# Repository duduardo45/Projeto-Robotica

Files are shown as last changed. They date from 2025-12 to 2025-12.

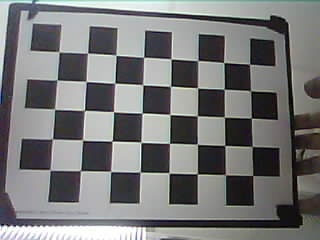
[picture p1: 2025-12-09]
ui/esp32_calibration_images/calib_20251209_100633.jpg

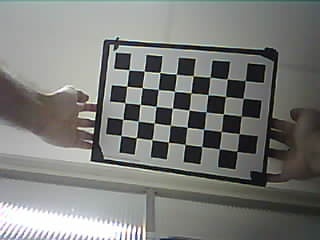
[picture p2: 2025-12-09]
ui/esp32_calibration_images/calib_20251209_100614.jpg

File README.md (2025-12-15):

# 🤖 Projeto Robótica - Empilhadeira Autônoma

Este repositório contém o projeto completo de uma empilhadeira autônoma desenvolvido para a disciplina de Robótica da PUC-Rio no semestre 2025.2. O curso tem como objetivo projetar e construir um robô funcional capaz de operar de forma autônoma e remota.

## 👥 Equipe

- Eduardo Eugênio de Souza
- Enzo Mediano
- Luísa Ferreira da Silveira
- Luiz Felipe Neves Batista

## 🎯 Objetivo do Projeto

O desafio proposto foi desenvolver uma empilhadeira autônoma com os seguintes requisitos:

- **Interface remota** para controle manual e controle de missão
- **Carga máxima**: 1 Kg
- **Altura máxima** do levantamento do garfo: 15 cm
- **Leitura de AprilTags** para localização no terreno e identificação de pallets
- **Alimentação** por baterias 18650

## Arquitetura do Sistema

O projeto foi desenvolvido seguindo uma abordagem integrada de hardware e software, dividido em 5 soluções principais:

---

## 1️⃣ Solução Mecânica

### Projeto e Construção

Todas as peças estruturais foram projetadas em CAD e impressas em 3D. Os arquivos STL estão disponíveis na pasta [Modelagem3D](Modelagem3D/).

#### **Componentes Mecânicos Projetados:**

**Garfo e Sistema de Elevação:**

- [Guia + Garfo - Part 1](<Modelagem3D/Guia%20+%20Garfo%20-%20Part%201%20(4).stl>) - Estrutura principal do garfo
- [Guia + Garfo - Part 2](<Modelagem3D/Guia%20+%20Garfo%20-%20Part%202%20(3).stl>) - Componente secundário do garfo
- [Guia + Garfo - Part 4](Modelagem3D/Guia%20+%20Garfo%20-%20Part%204.stl) - Suporte adicional
- Guia vertical de **15 cm** para elevação do garfo
- Sistema de polias para transmissão ([Polia - Part 1](Modelagem3D/Polia%20-%20Part%201.stl))

**Estrutura e Suportes:**

- [Case Baterias](Modelagem3D/Case_Baterias%20-%20Part%201.stl) - Compartimento para baterias 18650
- [Case Contrapeso](Modelagem3D/Case-Contrapeso%20-%20Part%202.stl) - Peso para balanceamento
- [Suporte ESP32 - Part 1](<Modelagem3D/Suporte%20esp32%20-%20Part%201%20(1).stl>) e [Part 2](<Modelagem3D/Suporte%20esp32%20-%20Part%202%20(1).stl>) - Fixação do microcontrolador
- [Roof Holder - Parts 1-4](Modelagem3D/) - Suportes para o teto do robô
- [Suporte Motor Elevação](Modelagem3D/suporte%20motor%20elevação%20-%20Part%201.stl) - Base do motor de elevação

#### **Modelagens Não Utilizadas:**

Algumas peças foram modeladas mas não foram utilizadas na montagem final:

- [Battery Support (Suporte de Bateria)](Modelagem3D/Battery%20Container%20Support.stl) - Não foi utilizado pois se tornou redundante, já que o compartimento de baterias conseguia ser travado através do teto (roof holder) e havia a necessidade de passagem de fios pela parte inferior do suporte.
- [Motor Holder (Suporte do Motor)](Modelagem3D/Motor%20Holder.stl) - Não houve tempo hábil para instalar o componente.
- [Polia](Modelagem3D/Polia%20-%20Part%201.stl) - A polia acabou não sendo utilizada, preferindo conectar o fio que levanta o garfo diretamente no motor.

#### **Limitações de Tempo na Montagem:**

1. **Motor Elevation Base** - Não foi impresso devido ao tempo limitado do projeto
2. **Roof (teto completo)** - Foi impresso, mas não montado. Esta peça seguraria o motor de elevação que ficaria em cima do roof holder. Como não foi implementada, o motor de elevação permaneceu dentro do chassis do robô
3. **Organização de fiação** - Como a câmera utilizada era integrada ao ESP32 e ele ficou posicionado no alto (em cima da guia), muitos fios ficaram expostos e desorganizados, comprometendo a estética do projeto. Com mais tempo, seria implementada uma calha para passagem de fios na guia
4. **Polia** - Preferimos conectar os fios diretamente ao motor de elevação, sem utilizar a polia impressa. Isso simplificou a montagem e evitou possíveis problemas mecânicos"

### Montagem Final

O robô foi montado com:

- Garfo móvel com guia de elevação de 15cm
- sistema de passagem dos fios que puxam o garfo
- Compartimento de baterias integrado
- Teto para o chassis (roof holder)
- Contrapeso para balanceamento
- ESP32 com câmera posicionado na parte superior

---

## 2️⃣ Solução Eletrônica

### Componentes Utilizados

#### **Microcontrolador:**

- **ESP32-S3 DevKitC-1** (16MB Flash, PSRAM)
  - WiFi integrado para comunicação
  - Câmera OV2640 integrada (320x240)
  - 2x Timer hardware para controle preciso
  - Múltiplos canais PWM

#### **Sistema de Alimentação:**

- **3x Baterias 18650** em série → **12V total**
  - **12V direto** para os motores DC
  - ⚠️ **BMS não implementado** - Por limitação de tempo, não foi utilizado Battery Management System. Isso seria uma melhoria importante para segurança e longevidade das baterias

#### **Motorização:**

- **2x Motores DC com encoder** (locomoção)
  - 64 pulsos por rotação
  - Alimentação: 12V
  - Controle via Ponte H
- **1x Motor DC para elevação do garfo**
  - Hardware montado e conectado
  - ⚠️ Software não implementado

#### **Drivers e Interfaces:**

- **Ponte H (H-Bridge)** para controle bidirecional dos motores
  - Controle de direção (pinos IN1, IN2)
  - Controle de velocidade via PWM
  - Duas Ponte H (uma para motores de locomoção e uma para o de elevação)
- **Encoders ópticos** conectados via interrupção

## 3️⃣ Solução de Comunicação

### Arquitetura de Comunicação

O sistema utiliza uma arquitetura de três camadas:

```
[Frontend Web] ↔ [Backend Python] ↔ [ESP32]
   (React)      WebSocket/HTTP      WebSocket
```

### Protocolo de Comunicação

#### **ESP32 ↔ Backend Python:**

- **WebSocket** na porta 8000
- **Formato:** JSON (comandos e telemetria) + Binário (imagens)
- **Taxa de telemetria:** 20Hz (50ms)
- **Taxa de vídeo:** 5fps (200ms)

#### **Backend ↔ Frontend:**

- **WebSocket** para dados em tempo real
- **REST API** para comandos pontuais
- **Broadcast** de estado para múltiplos clientes

### Mecanismos de Fail-Safe

1. **Heartbeat System:**

   - Cliente deve enviar heartbeat a cada 200ms
   - Timeout de 3 segundos sem heartbeat → parada automática dos motores
   - Implementado via timestamp no ESP32

2. **Watchdog de Conexão:**

   - Detecção de desconexão WebSocket
   - Parada segura em caso de perda de comunicação

3. **Validação de Comandos:**
   - Limites de velocidade no firmware
   - Validação de JSON no backend

### Interface de Controle

- **Interface Web moderna** (React + TypeScript)
- **Controle manual** via botões de interface
- **Controle autônomo** via waypoints
- **Visualização em tempo real** de câmera e telemetria
- **Gráficos de debug** para ajuste de PID

---

## 4️⃣ Solução de Controle

### Controle em Malha Aberta vs Malha Fechada

O sistema implementa controle em **malha fechada** para os motores de locomoção, utilizando feedback dos encoders para correção contínua.

### 🎯 Controlador PID

O firmware implementa um controlador PID otimizado para cada roda:

#### **Componentes do Controlador:**

1. **Termo Proporcional (P):** `kp × erro`

   - Correção proporcional ao erro de velocidade
   - kp = 40.0 (ajustado experimentalmente)

2. **Termo Integral (I):** `ki × ∫erro·dt`

   - Elimina erro em regime permanente
   - ki = 30.0
   - **Anti-windup:** Limita integrador a ±6.0 para evitar saturação

3. **Feedforward (F):** `kf × velocidade_desejada`

   - Compensação antecipada da velocidade
   - kf = 10.0

4. **Termo Estático (S):** `ks`

   - Constante para vencer atrito estático inicial
   - ks = 120.0

5. **Dithering:**
   - Vibração de 25Hz (±70 PWM) para reduzir zona morta
   - Elimina stiction e melhora resposta em baixas velocidades

#### **Características do Sistema:**

- **Frequência de controle:** 33Hz (30ms de período)
- **Rampa de aceleração:** 0.4 m/s² máximo
- **Filtro passa-baixas:** α = 0.1 (suavização exponencial)
- **Encoders:** 64 pulsos/rotação
- **Thread-safe:** Mutex para proteção de variáveis compartilhadas

### 🗺️ Navegação e Localização

#### **Detecção de AprilTags:**

- Biblioteca `pupil_apriltags` para detecção
- Família de tags: 36h11
- Tamanho físico: 12cm
- Calibração de câmera: fx=298.3, fy=306.9, cx=158.8, cy=121.7

#### **Localização:**

- Cálculo de pose (x, y, θ) baseado em AprilTags detectadas
- Transformação 3D → 2D para navegação planar
- Fusão com odometria dos encoders

#### **Navegação Autônoma:**

- Waypoint navigation com correção de trajetória
- Controlador angular proporcional
- Tolerância: 5cm (posição), 0.5rad (orientação)
- Estados: idle, running, completed, error

---

## 5️⃣ Montagem Geral

### Processo de Montagem

A montagem do robô seguiu as seguintes etapas:

#### **1. Impressão 3D das Peças**

Todas as peças foram impressas utilizando os arquivos STL disponíveis:

- Estrutura do garfo e guias
- Compartimentos para eletrônica
- Suportes e fixações

#### **2. Montagem da Estrutura Base**

- Montagem do roof holder do robô
- Montagem do compartimento de baterias
- Instalação do contrapeso para balanceamento

#### **3. Montagem do Sistema de Elevação**

- Instalação da guia vertical (15cm)
- Fixação do garfo móvel
- Montagem do sistema onde passam os fios
- Conexão do motor de elevação (hardware pronto)

#### **4. Integração Eletrônica**

- Instalação do ESP32 no suporte superior
- Conexão da Ponte H aos motores
- Fiação das baterias (3x em série = 12V)
- Conexão dos encoders

#### **5. Limitações da Montagem**

**Problemas Estéticos:**

- Como a câmera é integrada ao ESP32 e foi posicionada no alto (em cima da guia), muitos fios ficaram expostos e desorganizados
- Isso comprometeu a aparência final do projeto
- **Solução planejada (não implementada):** Calha para passagem de fios na guia

**Componentes não Montados:**

- **Motor Elevation Base:** Não foi impresso por falta de tempo
- **Roof completo:** Foi impresso mas não montado. Esta peça seguraria o motor de elevação que ficaria em cima do roof holder
- Como resultado, o motor de elevação permaneceu dentro do chassis

**Sistema de Alimentação:**

- BMS (Battery Management System) não foi implementado
- Seria importante para segurança e longevidade das baterias
- Configuração atual: 3 baterias 18650 em série (12V total)

### Resultado Final

O robô foi montado com:

- ✅ Chassis estrutural completo
- ✅ Sistema de locomoção com 2 motores + encoders
- ✅ Garfo com guia de 15cm
- ✅ Sistema de passagem do fios
- ✅ ESP32 com câmera integrada
- ✅ Ponte H para controle dos motores
- ✅ Sistema de baterias (3x 18650 em série)
- ⚠️ Fiação exposta (sem calha organizadora)
- ⚠️ Motor de elevação sem software
- ⚠️ Roof não montado completamente

---

## 💻 Detalhes de Implementação de Software

### 🔧 Firmware ESP32 (C++)

Desenvolvido em C++ usando o framework Arduino para ESP32.

**Arquivos principais:**

- [main.cpp](src/main.cpp) - Loop principal e coordenação de sistemas
- [camera_pins.h](src/camera_pins.h) - Definição de pinos da câmera

### 🐍 Backend Python (FastAPI)

O servidor backend em Python atua como intermediário inteligente entre a interface do usuário e o robô.

**Arquivos principais:**

- [main.py](ui/main.py) - Servidor principal e lógica de controle
- [calibrate_camera.py](ui/calibrate_camera.py) - Calibração da câmera

**Arquivos para testes:**

- [fake_robot.py](ui/fake_robot.py) - Simulador para testes
- [simple_server.py](ui/simple_server.py) - Servidor simplificado
- [gabriel_client.py](ui/gabriel_client.py) - Cliente simples para testes

### ⚛️ Frontend Web (React + TypeScript)

Interface moderna e responsiva desenvolvida com React 18, TypeScript e Chakra UI.

**Funcionalidades:**

- Controle manual e autônomo
- Visualização de câmera em tempo real
- Gráficos de telemetria (velocidade, PID, PWM)
- Monitoramento de AprilTags
- Dashboard de estado do robô

**Arquivos principais:**

- [App.tsx](ui-frontend/src/App.tsx) - Componente principal
- [CameraFeed.tsx](ui-frontend/src/components/CameraFeed.tsx) - Visualização de vídeo
- [types.ts](ui-frontend/src/types.ts) - Definições de tipos
- [theme.ts](ui-frontend/src/theme.ts) - Configuração de tema

---

## ⚙️ Configuração e Execução

### ESP32 Firmware

```bash
# Instalar PlatformIO
pip install platformio

# Compilar e fazer upload
cd Projeto-Robotica
pio run --target upload
```

### Backend Python

```bash
cd ui
pip install -e .
python main.py
```

### Frontend

```bash
cd ui-frontend
pnpm install
pnpm dev
```

---

## 🎮 Modos de Operação

### 1. Modo Manual

- Controle direto via interface web ou cliente Python
- Comandos via botões de interface para movimento
- Feedback em tempo real de telemetria

### 2. Modo Autônomo

- Definição de waypoint de destino via interface
- Navegação automática com correção de trajetória
- Localização baseada em AprilTags
- Parada automática ao atingir objetivo

## 📊 Características Técnicas do Software

### Controle PID Otimizado

- **Frequência**: 33Hz (30ms de período)
- **Dithering**: implementado para redução de stiction
- **Anti-windup**: Clamp do integrador em ±6.0
- **Rampa**: Aceleração máxima de 0.4 m/s²
- **Filtro**: α = 0.1 para suavização exponencial

### Comunicação

- **Protocolo**: WebSocket (texto JSON + binário)
- **Telemetria**: 20Hz
- **Vídeo**: 5fps (320x240 JPEG)
- **Heartbeat**: 5Hz com timeout de 3s

### Visão Computacional

- **Tags**: Família AprilTag 36h11
- **Tamanho**: 12cm (físico)
- **Calibração**: Fx=298.3, Fy=306.9, Cx=158.8, Cy=121.7
- **Detecção**: Tempo real (<50ms por frame)

## ⚠️ Limitações e Trabalho Futuro

### ❌ O que não foi implementado

#### **Sistema de Elevação do Garfo**

Infelizmente, não tivemos tempo de implementar o código de controle para o motor de elevação do garfo. A **parte mecânica e eletrônica estava completa**, incluindo:

- Motor DC com encoder
- Sistema da passagem dos fios, guias e garfo impressas em 3D
- Driver de motor conectado ao ESP32

**O que faltou:** Implementação do código de controle no firmware, incluindo:

- Interface de comandos via WebSocket
- Controle de posição ou velocidade
- Limites de segurança (altura mínima/máxima)
- Integração com a interface gráfica

### 🚧 Desafios Encontrados

Durante o desenvolvimento, enfrentamos alguns desafios importantes que impactaram o desempenho do robô:

1. **Atrito excessivo no piso**

   - O tipo de piso utilizado nos testes apresentava muito atrito
   - Isso dificultou o movimento suave do robô
   - Exigiu ajustes constantes nos parâmetros do PID
   - Afetou a precisão da odometria

2. **Problemas mecânicos nas rodas**

   - As rodas não giravam perfeitamente livre
   - Havia resistência mecânica além do esperado
   - Possível desalinhamento ou fricção nos eixos
   - Zona morta maior que o ideal no sistema de acionamento

3. **Navegação autônoma imprecisa**

   - A navegação para pontos específicos não estava 100% precisa
   - Desvios acumulativos devido ao atrito e problemas mecânicos
   - Dificuldade em manter trajetória reta por longas distâncias
   - Necessidade de ajuste fino dos ganhos do controlador

4. **Latência na comunicação WiFi**
   - Atraso na transmissão de informações no modo manual
   - Possível instabilidade da conexão WiFi em tempo real
   - Impactou a responsividade e controle direto do robô
   - Comandos demoravam alguns milissegundos para chegar
   - Feedback de telemetria não era tão rápido quanto ideal

Estes problemas mecânicos, de atrito e de comunicação impactaram significativamente a performance do sistema autônomo e manual, demonstrando a importância da integração mecânica, eletrônica e de software em projetos de robótica.

### ✅ O que foi concluído com sucesso

1. **Sistema de locomoção**

   - Motores DC com controle PID implementado
   - Odometria funcional (com limitações pelo atrito)
   - Controle diferencial básico operacional

2. **Comunicação WiFi/WebSocket**

   - Conexão funcional (com latência perceptível no controle manual)
   - Protocolo bem definido e extensível

3. **Visão computacional**

   - Detecção confiável de AprilTags
   - Cálculo de pose implementado
   - Streaming de vídeo funcional

4. **Interface de usuário**

   - Interface moderna e intuitiva
   - Telemetria em tempo real
   - Gráficos de debug detalhados

5. **Navegação autônoma básica**
   - Waypoint navigation implementada
   - Correção de trajetória (com margem para melhorias)
   - Sistema de missões funcional

### 🔮 Melhorias Futuras

#### **Software - Comunicação**

- Otimizar comunicação WiFi para reduzir latência
- Implementar compressão de dados para mais rápida transmissão
- Aumentar frequência de heartbeat
- Otimizar protocolo WebSocket

#### **Software - Controle de Elevação**

- Implementar controle manual do garfo (subir/descer)
- Implementar controle autônomo do garfo em missões
- Integrar interface gráfica para controle da elevação

#### **Hardware e Mecânica**

- Pensar em estratégias para lidar com o atrito do piso
- Implementar BMS para segurança das baterias
- Imprimir as peças não montadas (Motor Elevation Base, Roof) e montá-las corretamente
- Adicionar sensor de fim de curso para detectar quando o pallet está posicionado
- Adicionar sensor ultrassônico para detecção de obstáculos

#### **Algoritmos Avançados**

- Implementar SLAM para mapeamento do ambiente
- Melhorar odometria com fusão de sensores (IMU)
- Adicionar planejamento de trajetória (A\*, RRT)
- Implementar pickup/place automático de pallets
- Adicionar sistema de filas de missões

---

## 🛠️ Dependências Principais

### ESP32

- Arduino Framework
- ArduinoJson (^7.0.4)
- ESP32 Camera (^2.0.4)
- WebSockets (^2.7.1)

### Python Backend

- FastAPI
- Uvicorn
- Websockets
- OpenCV (cv2)
- NumPy
- pupil-apriltags
- TurboJPEG

### Frontend

- React 18
- TypeScript
- Chakra UI
- Vite
- Lucide Icons

---

## 📝 Licença

Este projeto foi desenvolvido para fins educacionais como parte da disciplina de Robótica da PUC-Rio.

---

## 🙏 Agradecimentos

Agradecemos aos professores da disciplina de Robótica pelo suporte e orientação durante o desenvolvimento deste projeto desafiador.

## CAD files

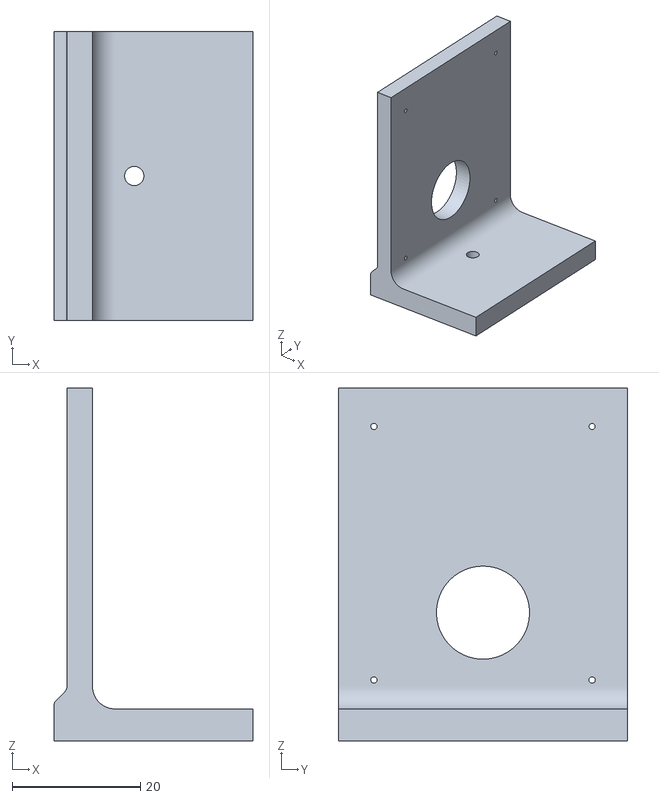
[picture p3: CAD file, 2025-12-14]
Modelagem3D/Motor Holder.stl
31.0 x 45.0 x 55.0

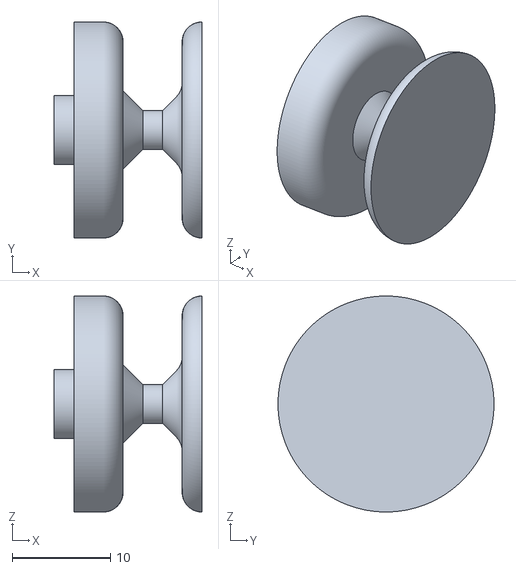
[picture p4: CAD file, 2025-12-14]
Modelagem3DNaoUtilizado/Polia - Part 1.stl
15.0 x 21.9 x 21.9

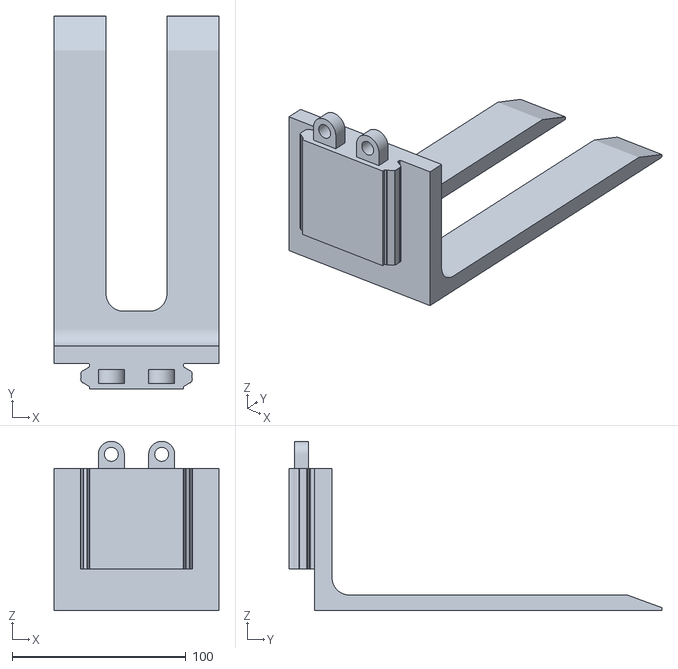
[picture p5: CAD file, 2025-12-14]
Modelagem3D/Guia + Garfo - Part 1 (4).stl
95.0 x 214.8 x 97.5

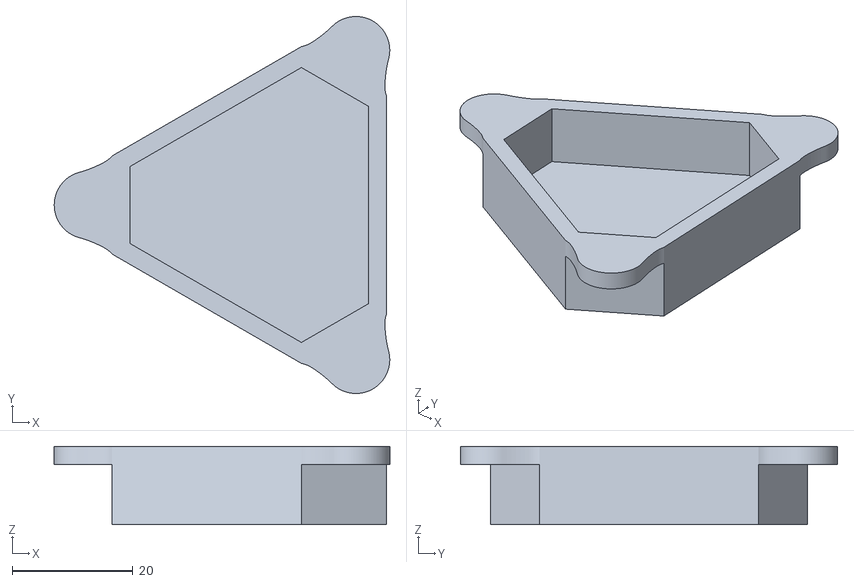
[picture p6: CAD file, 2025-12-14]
Modelagem3D/Case-Contrapeso - Part 2.stl
55.6 x 62.5 x 13.0

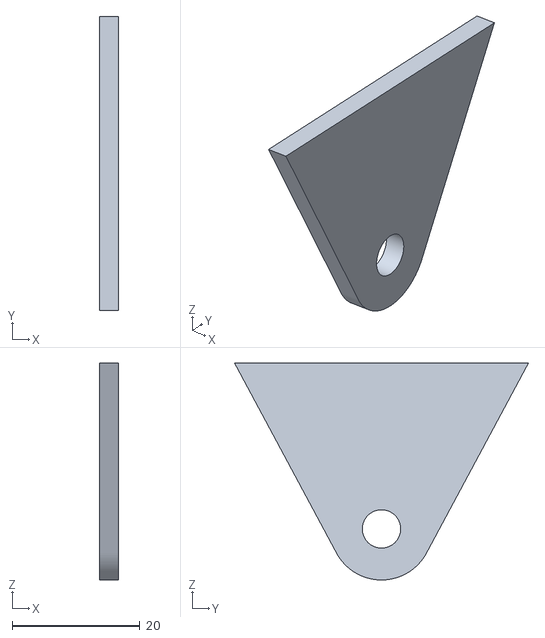
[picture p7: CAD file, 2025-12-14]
Modelagem3D/Roof holder - Part 2.stl
3.00 x 46.1 x 34.0

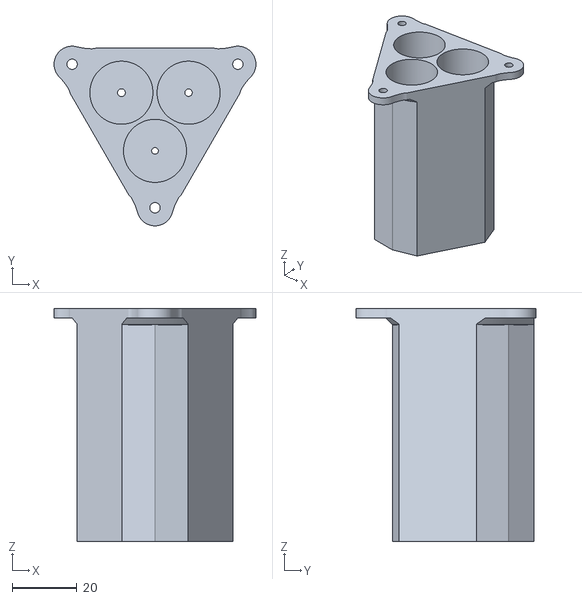
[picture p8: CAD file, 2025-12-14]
Modelagem3D/Case_Baterias - Part 1.stl
62.5 x 55.6 x 72.1

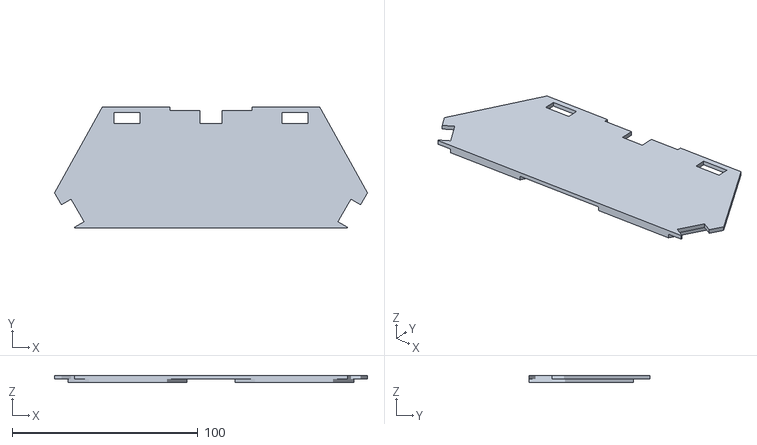
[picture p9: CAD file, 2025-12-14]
Modelagem3D/Battery Container Support.stl
168.5 x 65.3 x 4.00

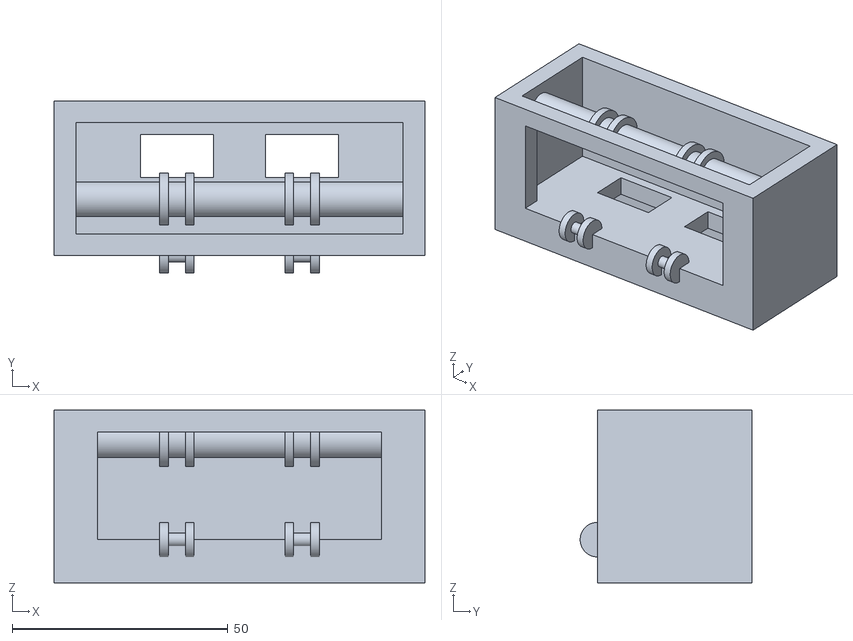
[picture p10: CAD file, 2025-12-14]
Modelagem3D/Guia + Garfo - Part 4.stl
86.0 x 39.8 x 40.0

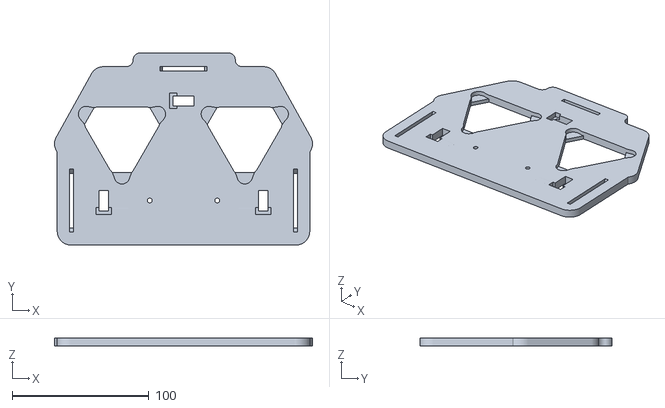
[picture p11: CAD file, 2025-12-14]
Modelagem3D/Roof holder - Part 4.stl
188.5 x 140.3 x 6.04

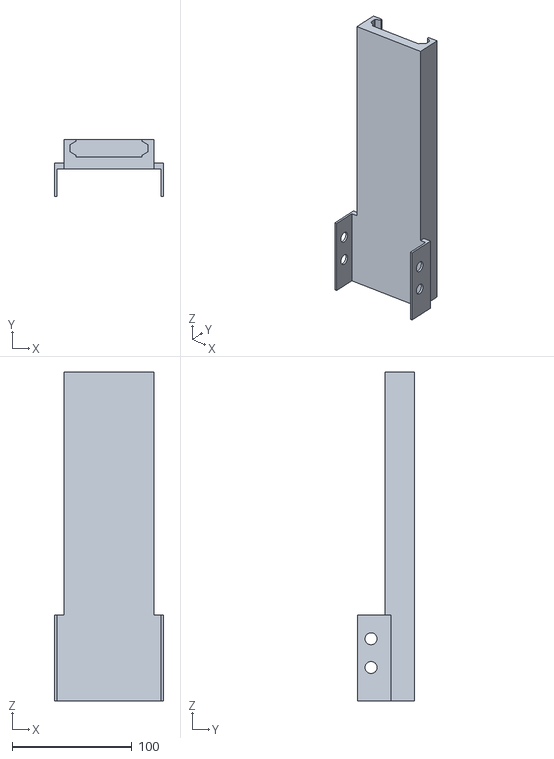
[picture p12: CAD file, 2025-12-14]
Modelagem3D/Guia + Garfo - Part 2 (3).stl
91.0 x 48.0 x 275.0

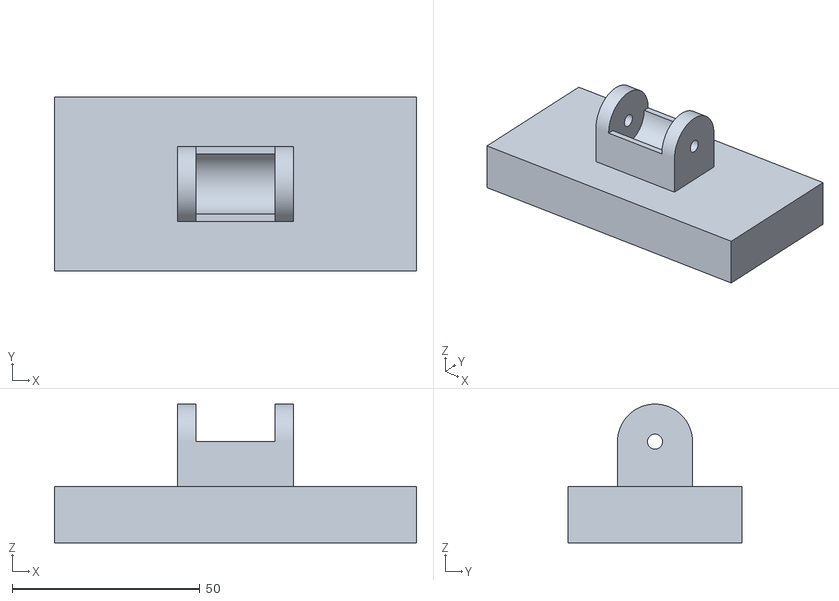
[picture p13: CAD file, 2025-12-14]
Modelagem3D/Suporte esp32 - Part 1 (1).stl
96.5 x 46.4 x 37.0

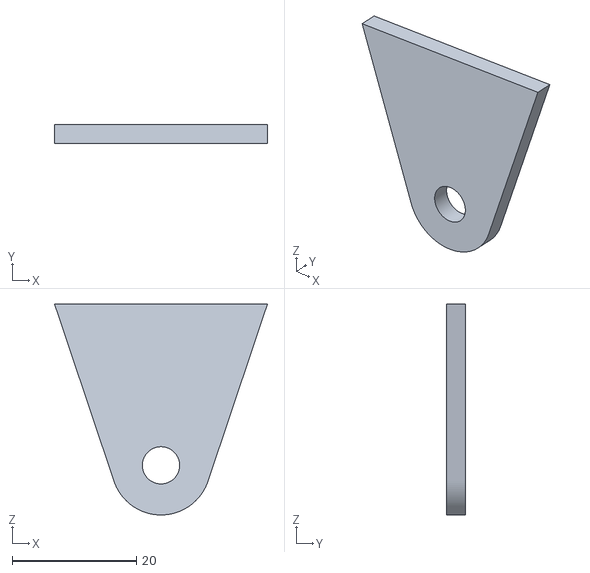
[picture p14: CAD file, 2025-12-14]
Modelagem3D/Roof holder - Part 3.stl
34.3 x 3.00 x 34.0

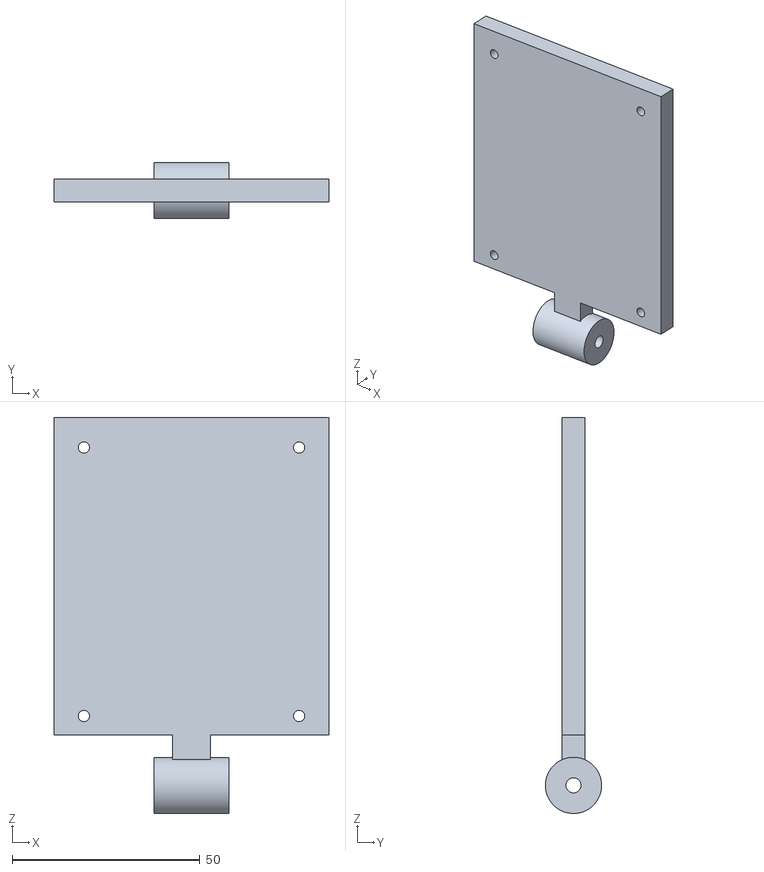
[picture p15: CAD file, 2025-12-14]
Modelagem3D/Suporte esp32 - Part 2 (1).stl
73.2 x 15.0 x 105.6

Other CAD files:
Modelagem3D/suporte motor elevação - Part 1.stl
Modelagem3D/Roof holder - Part 1.stl

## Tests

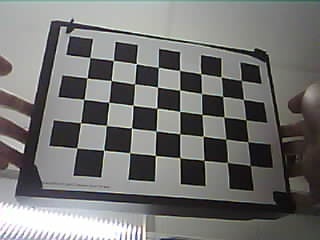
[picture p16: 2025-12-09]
ui/esp32_calibration_images/calib_20251209_100652.jpg

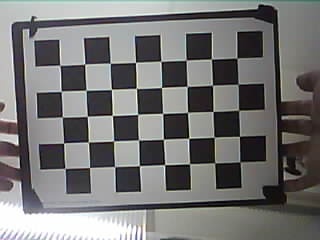
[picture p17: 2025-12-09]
ui/esp32_calibration_images/calib_20251209_100625.jpg

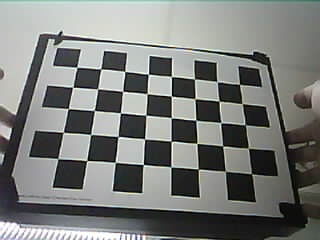
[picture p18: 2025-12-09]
ui/esp32_calibration_images/calib_20251209_100638.jpg

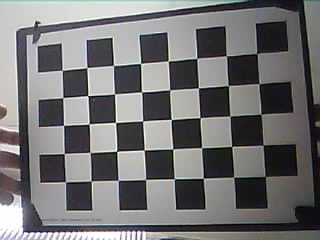
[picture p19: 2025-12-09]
ui/esp32_calibration_images/calib_20251209_100629.jpg

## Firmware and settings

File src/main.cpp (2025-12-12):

#include <Arduino.h>
#include <ArduinoJson.h>
#include <WebSocketsServer.h>
#include <WiFi.h>
#include <esp_camera.h>

#include "camera_pins.h"
// #include "credentials.h"
// DO NOT DO NEOPIXEL WRITE BECAUSE WE COULD BE USING ITS PIN
//
// CONFIGURATION
//

// --- Networking ---
const uint16_t WS_PORT = 8000;

const char *AP_SSID = "ESP32_Robot_AP";
const char *AP_PASS = "robot1234";  // Must be at least 8 chars

// #define WHEELS_DISABLED
// --- Physics & Tuning ---
// Left Wheel
#define PIN_ENC_L 21
#define PIN_PWM_L 1
#define PIN_IN1_L 44
#define PIN_IN2_L 2
#define PWM_CHAN_L 2  // Channel 0 is taken by Camera! Using 2.
#define TUNING_L {120.0, 10.0, 40.0, 30.0}  // {ks, kf, kp, ki}

// Right Wheel. it has a bigger ks because it has more static friction
#define PIN_ENC_R 47
#define PIN_PWM_R 42
#define PIN_IN1_R 41
#define PIN_IN2_R 48
#define PWM_CHAN_R 3
#define TUNING_R {120.0, 10.0, 40.0, 30.0}

#define WHEEL_RADIUS_MM 49.67
#define PULSES_PER_ROT 64.0
#define PWM_LIMITS {0, 255}
#define SPEED_DEADBAND 0.01
#define INTEGRATOR_CLAMP 6.0
// SPEED_FILTER_ALPHA the lower you make it, the slower is the exponential
// average:
#define SPEED_FILTER_ALPHA 0.1

#define MAX_ACCEL 0.4
#define DITHER_MAGNITUDE 70.0

// --- Timing ---
#define CONTROL_PERIOD_MICROS 30e3
#define TELEMETRY_PERIOD_MICROS \
  50e3  // to get accurate telemetry, maybe this needs to be faster than the
        // control loop?
#define FRAME_STREAM_PERIOD_MICROS 200e3
#define PWM_FREQ 5000
#define PWM_RES 8
#define HEARTBEAT_TIMEOUT_MICROS 3000e3
//

// DATA STRUCTURES
//

portMUX_TYPE timerMux = portMUX_INITIALIZER_UNLOCKED;
// Mutex for protecting variables shared between loop() and motorTask()
portMUX_TYPE sharedVarMux = portMUX_INITIALIZER_UNLOCKED;

esp_timer_handle_t controlTimer;

struct PidConfig {
  double ks, kf, kp, ki;
};

// --- THREAD SAFETY BRIDGE ---
struct MotorCommand {
  double targetL;
  double targetR;
  int64_t lastHeartbeat;
};

struct MotorState {
  double encL, rawL, filtL, targetL;
  double encR, rawR, filtR, targetR;
  double debug_fL, debug_pL, debug_iL, debug_outL;
  double debug_fR, debug_pR, debug_iR, debug_outR;
};

// Global instances of the bridge data
MotorCommand sharedCommand = {0, 0, 0};
MotorState sharedState = {0};

//

// WHEEL CONTROLLER CLASS
//

class WheelController {
 public:
  const int pwmChannel;
  const int pinPwm;
  const int pinIn1;
  const int pinIn2;
  const int pinEnc;
  // State
  volatile unsigned long encoderCount = 0;
  unsigned long lastEncoderCount = 0;

  double targetSpeed = 0.0;     // m/s
  double internalTarget = 0.0;  // m/s (ramped target)
  double filteredSpeed = 0.0;   // m/s (filtered)
  double rawSpeed = 0.0;        // m/s (instant)
  double filteredRpm = 0.0;
  double integrator = 0.0;
  bool ditherState = false;

  double debug_p = 0;
  double debug_i = 0;
  double debug_f = 0;
  double debug_out = 0;

  WheelController(const PidConfig pid, const int pwmChannel, const int pinPwm,
                  const int pinIn1, const int pinIn2, const int pinEnc)
      : _pid(pid),
        pwmChannel(pwmChannel),
        pinPwm(pinPwm),
        pinIn1(pinIn1),
        pinIn2(pinIn2),
        pinEnc(pinEnc) {
    // Pre-calculate physics constant
    double circumference = 2 * M_PI * (WHEEL_RADIUS_MM / 1000.0);
    _metersPerPulse = circumference / PULSES_PER_ROT;
  }

  void begin() {
    pinMode(pinIn1, OUTPUT);
    pinMode(pinIn2, OUTPUT);
    pinMode(pinEnc, INPUT);

    // --- Use ledcAttachPin ---
    ledcSetup(pwmChannel, PWM_FREQ, PWM_RES);
    ledcAttachPin(pinPwm, pwmChannel);
    ledcWrite(pwmChannel, 0);
    stop();
  }

  // Call from ISR
  void IRAM_ATTR handleInterrupt() {
#ifdef WHEELS_DISABLED
    encoderCount = 0;
#else
    encoderCount++;
#endif
  }

  void stop() {
    digitalWrite(pinIn1, LOW);
    digitalWrite(pinIn2, LOW);
    ledcWrite(pwmChannel, 0);
    targetSpeed = 0;
    internalTarget = 0;
    integrator = 0;
  }

  void update() {
    // 1. Atomic Encoder Read
    unsigned long currentCount;
    noInterrupts();
    currentCount = encoderCount;
    interrupts();

    // 2. High Precision Time Calculation
    int64_t currentMicros = esp_timer_get_time();
    int64_t dtMicros = currentMicros - lastMicros;
    lastMicros = currentMicros;  // Update this immediately

    // Sanity check (prevent divide by zero or overflow on first run)
    if (dtMicros < 100) return;

    double dtSec = dtMicros / 1000000.0;

    // 3. Calculate Speed
    long delta = currentCount - lastEncoderCount;
    lastEncoderCount = currentCount;

    double instantSpeed = 0.0;

    if (delta != 0) {
      // We moved! Update the speed normally
      instantSpeed = ((double)delta / dtSec) * _metersPerPulse;
      lastPulseMicros = currentMicros;  // Reset timeout timer
    } else {
      // We did NOT move this loop.
      // Check how long it has been since the last move.
      // If > 100ms (0.1s), force speed to 0.
      if ((currentMicros - lastPulseMicros) > 200e3) {
        instantSpeed = 0.0;
        filteredSpeed = 0.0;  // Force filter reset
      } else {
        // We haven't moved *this* X ms, but we moved recently.
        // Keep instantSpeed as 0, but let the Low Pass Filter
        // naturally decay the measuredSpeed down.
        instantSpeed = 0.0;
      }
    }

    rawSpeed = instantSpeed;

    // 4. Low Pass Filter
    filteredSpeed = (SPEED_FILTER_ALPHA * instantSpeed) +
                    ((1.0 - SPEED_FILTER_ALPHA) * filteredSpeed);

    filteredRpm = (filteredSpeed / _metersPerPulse) * 60.0 / PULSES_PER_ROT;

    // 5. Ramping (The Wedge)
    // Move the internal target towards the real target slowly
    double max_step = MAX_ACCEL * dtSec;

    if (targetSpeed > internalTarget) {
      internalTarget += max_step;
      if (internalTarget > targetSpeed) internalTarget = targetSpeed;
    } else if (targetSpeed < internalTarget) {
      internalTarget -= max_step;
      if (internalTarget < targetSpeed) internalTarget = targetSpeed;
    }

    // 6. Control Logic
    bool forward = (targetSpeed >= 0);
    digitalWrite(pinIn1, forward ? HIGH : LOW);
    digitalWrite(pinIn2, forward ? LOW : HIGH);

    double targetAbs = fabs(internalTarget);
    double error = targetAbs - filteredSpeed;

    // Integral Anti-windup
    if (targetAbs < SPEED_DEADBAND) {
      integrator = 0;
    } else {
      integrator += error * dtSec;
      integrator = constrain(integrator, -INTEGRATOR_CLAMP, INTEGRATOR_CLAMP);
    }

    // 7. Calculate Output

    double pid_out = 0.0;
    if (targetAbs > 0.01) {
      // Break it down for logging
      debug_f = _pid.kf * targetAbs;
      debug_p = _pid.kp * error;
      debug_i = _pid.ki * integrator;

      pid_out = _pid.ks + debug_f + debug_p + debug_i;
    } else {
      debug_f = 0;
      debug_p = 0;
      debug_i = 0;
    }

    // 8. Dithering (The Lubricant)
    // Flip sign every loop (20ms).
    // This creates a 25Hz vibration.
    int dither = (ditherState) ? DITHER_MAGNITUDE : -DITHER_MAGNITUDE;
    ditherState = !ditherState;  // Toggle for next time
    // Only dither if we are trying to move
    if (fabs(internalTarget) < 0.001) dither = 0;
    double finalOutput = pid_out + dither;

    debug_out = finalOutput;  // Store unconstrained output

    int pwm = (int)constrain(round(finalOutput), 0.0, 255.0);

    ledcWrite(pwmChannel, pwm);
  }

 private:
  PidConfig _pid;
  double _metersPerPulse;
  int64_t lastMicros = 0;
  int64_t lastPulseMicros = 0;
};

//

// GLOBALS & INSTANCES
//

WebSocketsServer webSocket = WebSocketsServer(WS_PORT);
// Instantiate Left Wheel
WheelController leftWheel(TUNING_L, PWM_CHAN_L, PIN_PWM_L, PIN_IN1_L, PIN_IN2_L,
                          PIN_ENC_L);

// Instantiate Right Wheel
WheelController rightWheel(TUNING_R, PWM_CHAN_R, PIN_PWM_R, PIN_IN1_R,
                           PIN_IN2_R, PIN_ENC_R);

// ISR Wrappers (Required because we can't attach class methods directly to
// interrupts)
void IRAM_ATTR isrLeft() { leftWheel.handleInterrupt(); }
void IRAM_ATTR isrRight() { rightWheel.handleInterrupt(); }

//

// NETWORK HELPERS
//

void setupAccessPoint() {
  Serial.println("Setting up Access Point...");

  // Set WiFi to Access Point Mode
  WiFi.mode(WIFI_AP);
  WiFi.setSleep(false);

  // Configure the AP
  // (Optional: You can configure specific IP, Gateway, Subnet here if needed,
  // but default 192.168.4.1 is fine)

  bool result = WiFi.softAP(AP_SSID, AP_PASS);

  if (result) {
    Serial.println("AP Created Successfully");
    Serial.print("AP IP Address: ");
    Serial.println(WiFi.softAPIP());  // Should print 192.168.4.1
  } else {
    Serial.println("AP Creation Failed!");
  }
}

void handleIncomingJson(String data) {
  JsonDocument doc;
  if (deserializeJson(doc, data)) {
    Serial.println(F("JSON Error"));
    return;
  }

  const char *messageType = doc["message_type"] | "";

  if (strcmp(messageType, "command") == 0) {
    double newLeft = doc["left"] | 0.0;
    double newRight = doc["right"] | 0.0;

    portENTER_CRITICAL(&sharedVarMux);
    sharedCommand.targetL = newLeft;
    sharedCommand.targetR = newRight;
    portEXIT_CRITICAL(&sharedVarMux);

    Serial.printf("Target Left: %.3f\n", leftWheel.targetSpeed);
    Serial.printf("Target Right: %.3f\n", rightWheel.targetSpeed);

  } else if (strcmp(messageType, "heartbeat") == 0) {
    portENTER_CRITICAL(&sharedVarMux);
    sharedCommand.lastHeartbeat = esp_timer_get_time();
    portEXIT_CRITICAL(&sharedVarMux);
  }
}

void webSocketEvent(uint8_t num, WStype_t type, uint8_t *payload,
                    size_t length) {
  switch (type) {
    case WStype_DISCONNECTED:
      Serial.printf("[%u] Disconnected!\n", num);
      break;
    case WStype_CONNECTED: {
      IPAddress ip = webSocket.remoteIP(num);
      Serial.printf("[%u] Connected from %d.%d.%d.%d url: %s\n", num, ip[0],
                    ip[1], ip[2], ip[3], payload);
    } break;
    case WStype_TEXT: {
      String data = String((char *)payload);
      handleIncomingJson(data);
    } break;
    case WStype_BIN:
      Serial.printf("[%u] get binary length: %u\n", num, length);
      break;
    case WStype_ERROR:
    case WStype_FRAGMENT_TEXT_START:
    case WStype_FRAGMENT_BIN_START:
    case WStype_FRAGMENT:
    case WStype_FRAGMENT_FIN:
      break;
  }
}

//

//         // TELEMETRY & CAMERA
//         //

void sendTelemetry() {
  if (webSocket.connectedClients() == 0) return;

  static int64_t lastTime = 0;
  int64_t now = esp_timer_get_time();
  if (now - lastTime < TELEMETRY_PERIOD_MICROS) return;
  lastTime = now;

  MotorState stateSnapshot;
  portENTER_CRITICAL(&sharedVarMux);
  stateSnapshot = sharedState;
  portEXIT_CRITICAL(&sharedVarMux);

  JsonDocument doc;
  doc["message_type"] = "telemetry";
  doc["timestamp"] = now;

  JsonObject left = doc["left"].to<JsonObject>();
  left["encoder"] = stateSnapshot.encL;
  left["raw_speed"] = stateSnapshot.rawL;
  left["filtered_speed"] = stateSnapshot.filtL;
  left["target_speed"] = stateSnapshot.targetL;
  left["debug_f"] = stateSnapshot.debug_fL;
  left["debug_p"] = stateSnapshot.debug_pL;
  left["debug_i"] = stateSnapshot.debug_iL;
  left["debug_out"] = stateSnapshot.debug_outL;

  JsonObject right = doc["right"].to<JsonObject>();
  right["encoder"] = stateSnapshot.encR;
  right["raw_speed"] = stateSnapshot.rawR;
  right["filtered_speed"] = stateSnapshot.filtR;
  right["target_speed"] = stateSnapshot.targetR;
  right["debug_f"] = stateSnapshot.debug_fR;
  right["debug_p"] = stateSnapshot.debug_pR;
  right["debug_i"] = stateSnapshot.debug_iR;
  right["debug_out"] = stateSnapshot.debug_outR;

  String payload;
  serializeJson(doc, payload);
  webSocket.broadcastTXT(payload);
}

void setupCamera() {
  camera_config_t config;

  // 1. Pin Mappings (These constants come from camera_pins.h)
  config.ledc_channel = LEDC_CHANNEL_0;
  config.ledc_timer = LEDC_TIMER_0;
  config.pin_d0 = CAM_PIN_D0;
  config.pin_d1 = CAM_PIN_D1;
  config.pin_d2 = CAM_PIN_D2;
  config.pin_d3 = CAM_PIN_D3;
  config.pin_d4 = CAM_PIN_D4;
  config.pin_d5 = CAM_PIN_D5;
  config.pin_d6 = CAM_PIN_D6;
  config.pin_d7 = CAM_PIN_D7;
  config.pin_xclk = CAM_PIN_XCLK;
  config.pin_pclk = CAM_PIN_PCLK;
  config.pin_vsync = CAM_PIN_VSYNC;
  config.pin_href = CAM_PIN_HREF;
  config.pin_sccb_sda = CAM_PIN_SCCB_SDA;
  config.pin_sccb_scl = CAM_PIN_SCCB_SCL;
  config.pin_pwdn = CAM_PIN_PWDN;
  config.pin_reset = CAM_PIN_RESET;

  config.xclk_freq_hz = 20000000;  // 20MHz XCLK

  // config.pixel_format = PIXFORMAT_GRAYSCALE;
  config.pixel_format = PIXFORMAT_JPEG;

  config.fb_location = CAMERA_FB_IN_PSRAM;

  config.frame_size = FRAMESIZE_QVGA;  // 320x240
  config.jpeg_quality =
      10;  // 0-63. 10-12 is good balance. Lower is higher quality
  config.fb_count = 2;
  config.grab_mode = CAMERA_GRAB_LATEST;

  // 4. Initialize
  esp_err_t err = esp_camera_init(&config);
  if (err != ESP_OK) {
    Serial.printf("Camera init failed with error 0x%x", err);
    return;
  }

  sensor_t *s = esp_camera_sensor_get();

  Serial.println("Camera Configured Successfully");
}

void streamCamera(int64_t now) {
  static int64_t lastFrame = 0;

  if (now - lastFrame < FRAME_STREAM_PERIOD_MICROS) return;
  if (webSocket.connectedClients() == 0) return;

  camera_fb_t *fb = esp_camera_fb_get();
  if (!fb) {
    Serial.println("Couldn't get fb");
    return;
  };

  int64_t sendStart = esp_timer_get_time();
  webSocket.broadcastBIN(fb->buf, fb->len);
  int64_t sendEnd = esp_timer_get_time();
  int64_t sendDuration = sendEnd - sendStart;
  Serial.printf("[Send] Frame size: %zu bytes, Time: %lld us (%.3f ms)\n",
                fb->len, sendDuration, sendDuration / 1000.0);
  lastFrame = now;

  esp_camera_fb_return(fb);
}

// Task Handle to manage the task if needed
TaskHandle_t motorTaskHandle = NULL;

// void motorTask(void *parameter) {
//   const TickType_t xFrequency = pdMS_TO_TICKS(20);
//   TickType_t xLastWakeTime = xTaskGetTickCount();

//   for (;;) {
//     vTaskDelayUntil(&xLastWakeTime, xFrequency);

//     // --- PHASE 1: IMPORT DATA (CRITICAL SECTION) ---
//     double tL, tR;
//     int64_t hb;

//     portENTER_CRITICAL(&sharedVarMux);
//     tL = sharedCommand.targetL;
//     tR = sharedCommand.targetR;
//     hb = sharedCommand.lastHeartbeat;
//     portEXIT_CRITICAL(&sharedVarMux);

//     // --- PHASE 2: LOGIC & PHYSICS (NO LOCKS REQUIRED) ---
//     // The wheels are "private" to this task now. safely write to them.

//     // Failsafe Logic
//     int64_t now = esp_timer_get_time();
//     if (hb > 0 && (now - hb) > HEARTBEAT_TIMEOUT_MICROS) {
//       leftWheel.stop();
//       rightWheel.stop();
//       // Optional: Update shared heartbeat to 0 to signal stop?
//       // Usually not strictly necessary if client sends new hb later.
//     } else {
//       leftWheel.targetSpeed = tL;
//       rightWheel.targetSpeed = tR;

//       leftWheel.update();
//       rightWheel.update();
//     }

//     // --- PHASE 3: EXPORT DATA (CRITICAL SECTION) ---
//     portENTER_CRITICAL(&sharedVarMux);
//     sharedState.encL = leftWheel.encoderCount;
//     sharedState.filtL = leftWheel.filteredSpeed;
//     sharedState.targetL = leftWheel.targetSpeed;
//     sharedState.debug_fL = leftWheel.debug_f;
//     sharedState.debug_pL = leftWheel.debug_p;
//     sharedState.debug_iL = leftWheel.debug_i;
//     sharedState.debug_outL = leftWheel.debug_out;

//     sharedState.encR = rightWheel.encoderCount;
//     sharedState.filtR = rightWheel.filteredSpeed;
//     sharedState.targetR = rightWheel.targetSpeed;
//     sharedState.debug_fR = rightWheel.debug_f;
//     sharedState.debug_pR = rightWheel.debug_p;
//     sharedState.debug_iR = rightWheel.debug_i;
//     sharedState.debug_outR = rightWheel.debug_out;
//     portEXIT_CRITICAL(&sharedVarMux);
//   }
// }

void IRAM_ATTR onControlLoop(void *arg) {
  // --- PHASE 1: IMPORT DATA (CRITICAL SECTION) ---
  double tL, tR;
  int64_t hb;

  // Use a spinlock (portMUX) which is safe in ISRs
  portENTER_CRITICAL_ISR(&sharedVarMux);
  tL = sharedCommand.targetL;
  tR = sharedCommand.targetR;
  hb = sharedCommand.lastHeartbeat;
  portEXIT_CRITICAL_ISR(&sharedVarMux);

  // --- PHASE 2: LOGIC & PHYSICS ---
  int64_t now = esp_timer_get_time();

  // Failsafe Logic
  if (hb > 0 && (now - hb) > HEARTBEAT_TIMEOUT_MICROS) {
    leftWheel.stop();
    rightWheel.stop();
  } else {
    leftWheel.targetSpeed = tL;
    rightWheel.targetSpeed = tR;

    leftWheel.update();
    rightWheel.update();
  }

  // --- PHASE 3: EXPORT DATA ---
  portENTER_CRITICAL_ISR(&sharedVarMux);
  sharedState.encL = leftWheel.encoderCount;
  sharedState.filtL = leftWheel.filteredSpeed;
  sharedState.targetL = leftWheel.targetSpeed;
  sharedState.debug_fL = leftWheel.debug_f;
  sharedState.debug_pL = leftWheel.debug_p;
  sharedState.debug_iL = leftWheel.debug_i;
  sharedState.debug_outL = leftWheel.debug_out;

  sharedState.encR = rightWheel.encoderCount;
  sharedState.filtR = rightWheel.filteredSpeed;
  sharedState.targetR = rightWheel.targetSpeed;
  sharedState.debug_fR = rightWheel.debug_f;
  sharedState.debug_pR = rightWheel.debug_p;
  sharedState.debug_iR = rightWheel.debug_i;
  sharedState.debug_outR = rightWheel.debug_out;
  portEXIT_CRITICAL_ISR(&sharedVarMux);
}

//
// MAIN
//

void setup() {
  Serial.begin(115200);
  delay(1000);

  setupCamera();

  setupAccessPoint();

  // Hardware Setup
  leftWheel.begin();
  attachInterrupt(digitalPinToInterrupt(leftWheel.pinEnc), isrLeft, CHANGE);

  rightWheel.begin();
  attachInterrupt(digitalPinToInterrupt(rightWheel.pinEnc), isrRight, CHANGE);

  // WebSocket Server Setup
  webSocket.onEvent(webSocketEvent);
  webSocket.begin();
  IPAddress IP = WiFi.softAPIP();
  Serial.print("WebSocket server started on ws://");
  Serial.print(IP);
  Serial.print(":");
  Serial.println(WS_PORT);

  const esp_timer_create_args_t periodic_timer_args = {
      .callback = &onControlLoop, .name = "control_loop"};

  ESP_ERROR_CHECK(esp_timer_create(&periodic_timer_args, &controlTimer));

  // Start the timer.
  // 10000 micros = 10ms (100Hz Control Loop).
  // This gives a 50Hz Dither frequency, which is much smoother.
  ESP_ERROR_CHECK(
      esp_timer_start_periodic(controlTimer, CONTROL_PERIOD_MICROS));

  Serial.println("High-Precision Control Loop Started");
}

void loop() {
  int64_t now = esp_timer_get_time();

  webSocket.loop();

  sendTelemetry();
  streamCamera(now);
}

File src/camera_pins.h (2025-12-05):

#pragma once

#define CAM_PIN_PWDN -1
#define CAM_PIN_RESET -1
#define CAM_PIN_XCLK 15
#define CAM_PIN_SCCB_SDA 4
#define CAM_PIN_SCCB_SCL 5

#define CAM_PIN_D7 16
#define CAM_PIN_D6 17
#define CAM_PIN_D5 18
#define CAM_PIN_D4 12
#define CAM_PIN_D3 10
#define CAM_PIN_D2 8
#define CAM_PIN_D1 9
#define CAM_PIN_D0 11
#define CAM_PIN_VSYNC 6
#define CAM_PIN_HREF 7
#define CAM_PIN_PCLK 13

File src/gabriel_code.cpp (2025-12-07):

// #include <WebSocketsServer.h>
// #include <WiFi.h>
// #include <esp_camera.h>

// #include "camera_pins.h"

// // Note: Your original code used custom pins in the struct.
// // I have preserved YOUR specific pin mapping below.

// const char* network = "ponto_de_acesso";
// const char* password = "senha_foda";

// WebSocketsServer webSocket = WebSocketsServer(81);

// unsigned long lastFrameTime = 0;
// #define FRAME_INTERVAL 100  // Minimum ms between frames

// // --- FUNCTIONS ---

// void frame() {
//   camera_fb_t* frameBuffer = esp_camera_fb_get();

//   if (!frameBuffer) {
//     Serial.println("Camera capture failed!");
//     return;
//   }

//   // Send binary video data to all connected clients
//   int64_t t_before = esp_timer_get_time();
//   webSocket.broadcastBIN(frameBuffer->buf, frameBuffer->len);
//   int64_t t_after = esp_timer_get_time();
//   Serial.printf("Time to send frame: %lld us\n",
//                 (unsigned long long)t_after - t_before);
//   esp_camera_fb_return(frameBuffer);  // Release memory
// }

// void webSocketEvent(uint8_t num, WStype_t type, uint8_t* payload,
//                     size_t length) {
//   switch (type) {
//     case WStype_DISCONNECTED:
//       Serial.printf("[%u] Disconnected!\n", num);
//       break;
//     case WStype_CONNECTED: {
//       IPAddress ip = webSocket.remoteIP(num);
//       Serial.printf("[%u] Connected from %d.%d.%d.%d url: %s\n", num, ip[0],
//                     ip[1], ip[2], ip[3], payload);
//     } break;
//     case WStype_TEXT:
//       // We are just streaming video, but we print text if received for
//       // debugging
//       Serial.printf("[%u] get Text: %s\n", num, payload);
//       break;
//     case WStype_BIN:
//       Serial.printf("[%u] get binary length: %u\n", num, length);
//       break;
//     case WStype_ERROR:
//     case WStype_FRAGMENT_TEXT_START:
//     case WStype_FRAGMENT_BIN_START:
//     case WStype_FRAGMENT:
//     case WStype_FRAGMENT_FIN:
//       break;
//   }
// }

// // --- SETUP ---

// void setup() {
//   Serial.begin(115200);
//   delay(1000);

//   // WiFi Setup (AP Mode)
//   WiFi.softAP(network, password);
//   IPAddress IP = WiFi.softAPIP();
//   Serial.print("AP IP address: ");
//   Serial.println(IP);

//   // WebSocket Setup
//   webSocket.onEvent(webSocketEvent);
//   webSocket.begin();
//   Serial.println("WebSocket server started on ws://" + IP.toString() +
//   ":81");

//   camera_config_t config;

//   config.ledc_channel = LEDC_CHANNEL_0;
//   config.ledc_timer = LEDC_TIMER_0;
//   config.pin_d0 = CAM_PIN_D0;
//   config.pin_d1 = CAM_PIN_D1;
//   config.pin_d2 = CAM_PIN_D2;
//   config.pin_d3 = CAM_PIN_D3;
//   config.pin_d4 = CAM_PIN_D4;
//   config.pin_d5 = CAM_PIN_D5;
//   config.pin_d6 = CAM_PIN_D6;
//   config.pin_d7 = CAM_PIN_D7;
//   config.pin_xclk = CAM_PIN_XCLK;
//   config.pin_pclk = CAM_PIN_PCLK;
//   config.pin_vsync = CAM_PIN_VSYNC;
//   config.pin_href = CAM_PIN_HREF;
//   config.pin_sccb_sda = CAM_PIN_SCCB_SDA;
//   config.pin_sccb_scl = CAM_PIN_SCCB_SCL;
//   config.pin_pwdn = CAM_PIN_PWDN;
//   config.pin_reset = CAM_PIN_RESET;

//   config.xclk_freq_hz = 20000000;  // 20MHz XCLK

//   // config.pixel_format = PIXFORMAT_GRAYSCALE;
//   // config.frame_size = FRAMESIZE_QVGA;
//   // config.jpeg_quality = 10;

//   // config.fb_count = 1;
//   // config.fb_location = CAMERA_FB_IN_PSRAM;
//   // config.grab_mode = CAMERA_GRAB_LATEST;

//   config.pixel_format = PIXFORMAT_JPEG;
//   config.frame_size = FRAMESIZE_QVGA;
//   config.jpeg_quality =
//       10;  // 0-63. 10-12 is good balance. Lower is higher quality
//   config.fb_count = 2;
//   config.grab_mode = CAMERA_GRAB_LATEST;

//   // Camera Init
//   esp_err_t err = esp_camera_init(&config);
//   if (err != ESP_OK) {
//     Serial.printf("Camera init failed with error 0x%x", err);
//     while (true);
//   }
// }

// // --- LOOP ---

// void loop() {
//   webSocket.loop();

//   unsigned long now = millis();

//   // Broadcast a new frame if enough time has passed
//   if (now - lastFrameTime > FRAME_INTERVAL) {
//     frame();
//     lastFrameTime = now;
//   }
// }

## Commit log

2025-11-12 two wheels, two encoders, mqtt commands for speed, and PI controller
2025-11-19 david's code, can be used to debug encoders
2025-11-19 using websockets instead of mqtt. no debounce on encoders. camera streaming things over websockets. PID not yet tuned.
2025-11-26 testado, funcionou! Tivemos que usar ledcWrite em vez de analogWrite porque simplesmente não tava dando nenhuma tensão. Também tunamos o PID razoavelmente.
2025-11-28 duas rodas, tunadas. debug de controle na ui.
2025-12-07 funcionando streaming eficiente de frames e também detecção de april tags (sem conexão com sistema de posição)
2025-12-08 disabling wheels possible
2025-12-08 better wheel disabled
2025-12-08 detecção de pose funcionando, aparentemente
2025-12-09 pwm dithering e outras coisas funcionando
2025-12-10 dithering teve menos efeito porque motor agia como indutor, diminuí a frequencia do dithering pra tentar melhorar
2025-12-10 será que telemetry tem que ser mais rápido?
2025-12-14 Fix typo in README.md regarding pulley
2025-12-14 Added Modelagems not used
    [Battery Container Support.stl, Motor Holder.stl, Polia - Part 1.stl]
2025-12-14 rereferenced the pieces since we agreed to put all pieces within the same folder
    [Battery Container Support.stl, Motor Holder.stl, Polia - Part 1.stl]
2025-12-14 Revise unused components and assembly details in README
    Updated the README to reflect changes in the project components and their usage during assembly.
